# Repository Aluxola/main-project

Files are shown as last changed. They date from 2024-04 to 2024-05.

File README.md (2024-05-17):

# main-project
# Micro-mouse System Power and Sensor Subsystems
# Overview
This repository contains the design and implementation files for the Power and Sensor subsystems of a robotic system developed as part of the EEE3088F_2024 project. The Power subsystem manages power distribution, voltage regulation, and battery management, while the Sensor subsystem handles sensing and feedback for the robot's environment.

# Power Subsystem Features
Power distribution to motors and electronic components
Voltage regulation for stable operation
Battery management functions for efficient use
Current limiting and safety features
Power switching capabilities for control
Efficiency optimization for energy savings
# Sensor Subsystem Features
Wall sensing using infrared sensors
LED indicators for wall detection
Interface with the processor board for feedback
Low power consumption design
Reliability and accuracy in sensing wall proximity
# Contents
## Power Module:
### Schematics: 
Contains the schematic diagrams of the power module circuitry.
### PCB Design: 
Includes the PCB layout design files for manufacturing the power module.

## Sensor Module:
### Schematics: 
Contains the schematic diagrams of the sensor module circuitry.
### PCB Design: 
Includes the PCB layout design files for manufacturing the sensor module.
### Code: 
Firmware or software code for interfacing the sensor module with the processor board.
## Requirements
### Hardware: 
List of components required for building the power and sensor modules.
### Software: 
Tools and software required for programming, testing, and interfacing with the modules.

# Contributors
Alulutho Mthitshana

Tlangelani Tembe

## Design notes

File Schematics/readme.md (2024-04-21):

This is where our schematics are uploaded.

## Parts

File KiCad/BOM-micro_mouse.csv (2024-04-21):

Comment | Designator | Footprint | LCSC
10uF | C1,C4 | C_0603_1608Metric | C19702
1K | R2,R4,R5 | R_0603_1608Metric | C21190
JS102011SAQN | S1 | SW_JS102011SAQN | C221660
1.2K | R1 | R_0603_1608Metric | C22765
LED | D2 | LED_0603_1608Metric | C2286
LED | D1 | LED_0805_2012Metric | C2297
2.2uF | C2 | C_0603_1608Metric | C23630
2.2K | R3 | R_0603_1608Metric | C4190
DRV8833PW | U2 | SOP65P640X120-16N | C50506
0.01uF | C3 | C_0603_1608Metric | C57112
TP4056 | U1 | SOP127P600X175-9N | C725790

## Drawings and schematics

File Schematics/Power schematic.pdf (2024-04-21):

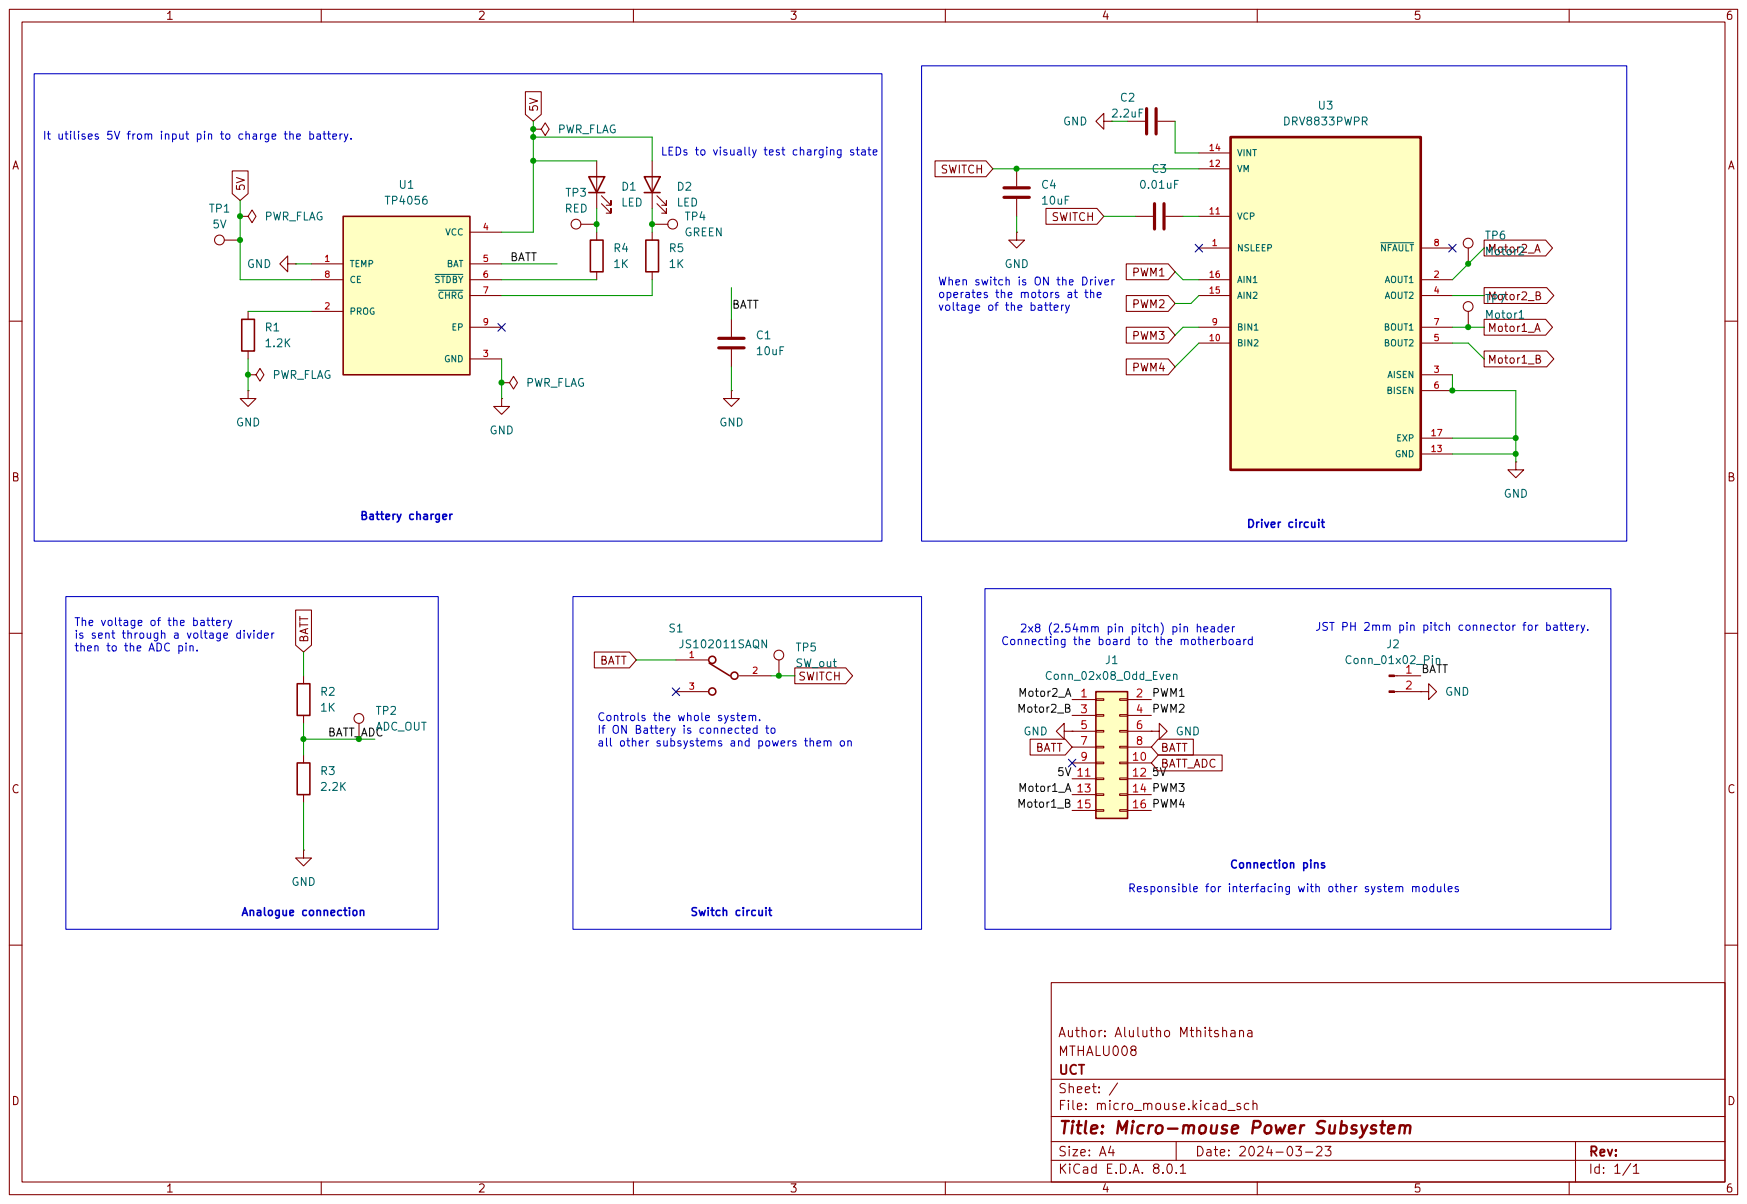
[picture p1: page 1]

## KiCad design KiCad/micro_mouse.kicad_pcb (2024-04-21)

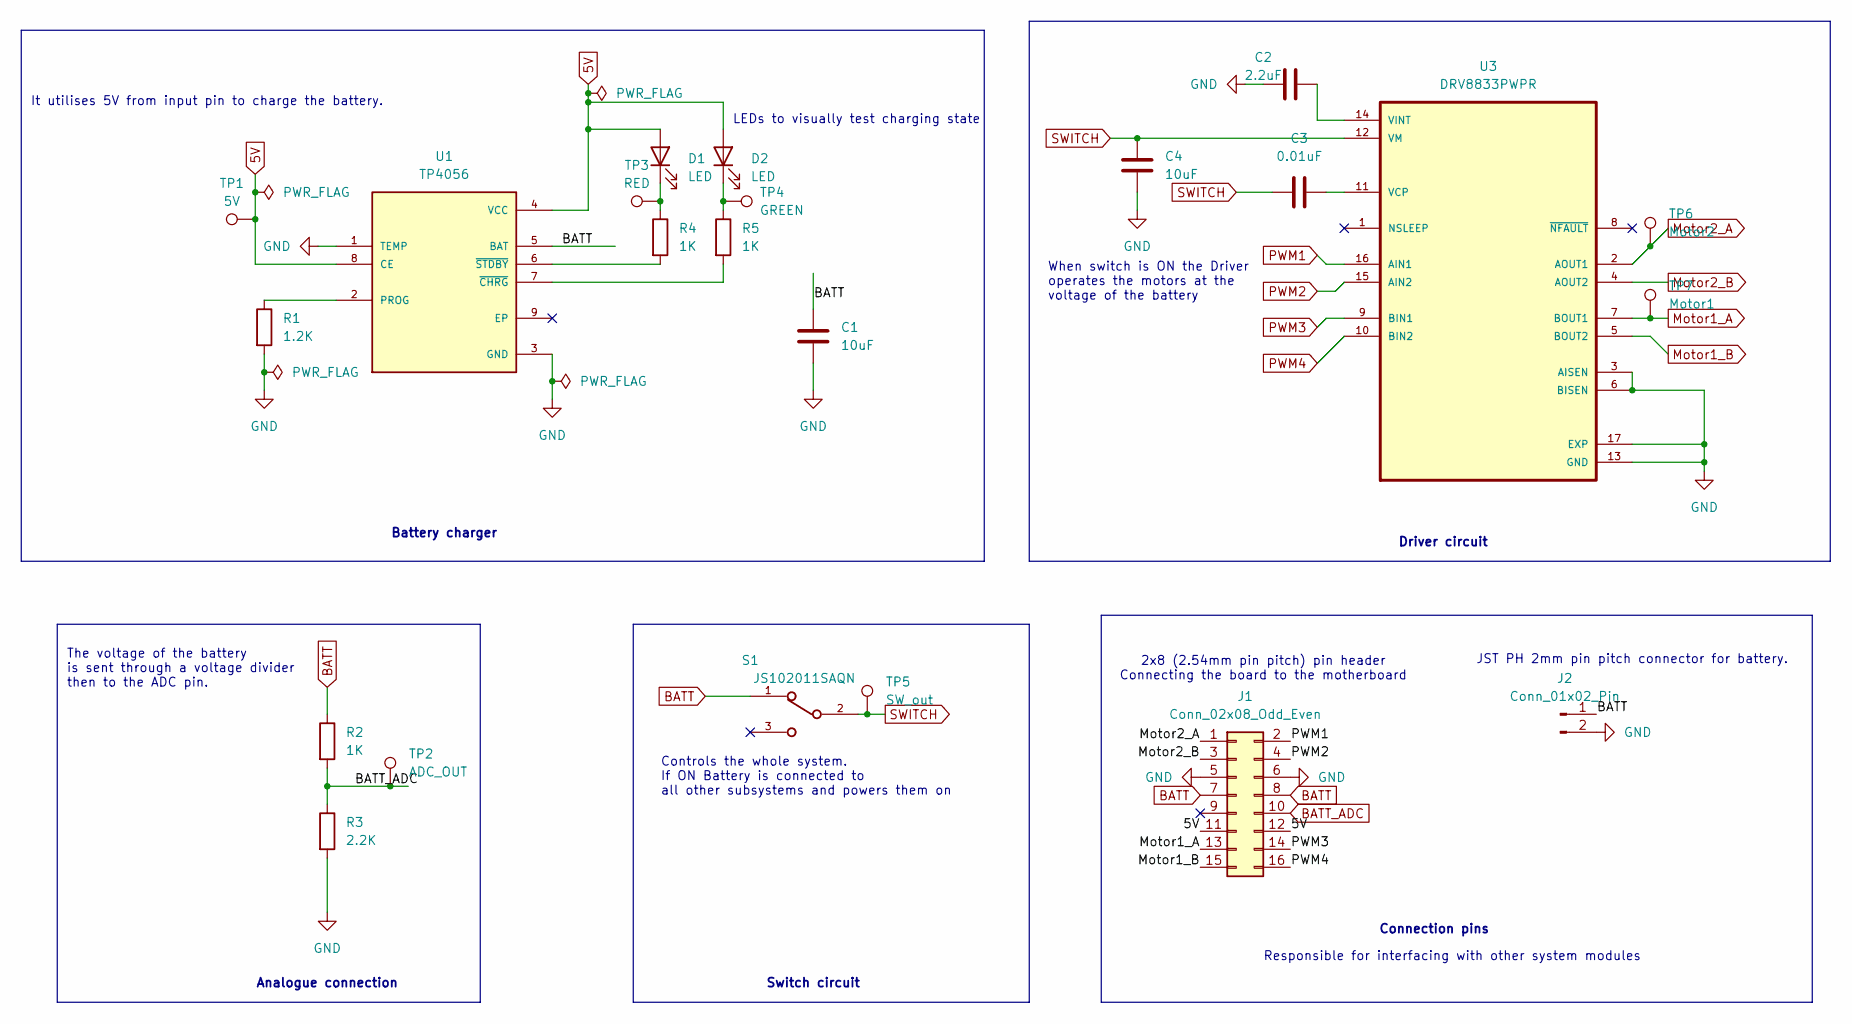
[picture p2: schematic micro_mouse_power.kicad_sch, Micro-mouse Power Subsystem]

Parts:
C1, C4: 10uF; C_0603_1608Metric
C2: 2.2uF; C_0603_1608Metric
C3: 0.01uF; C_0603_1608Metric
D1: LED; LED_0805_2012Metric
D2: LED; LED_0603_1608Metric
J1: Conn_02x08_Odd_Even; PinHeader_2x08_P2.54mm_Vertical
J2: Conn_01x02_Pin; JST_PH_B2B-PH-K_1x02_P2.00mm_Vertical
R1: 1.2K; R_0603_1608Metric
R2, R4, R5: 1K; R_0603_1608Metric
R3: 2.2K; R_0603_1608Metric
S1: JS102011SAQN; SW_JS102011SAQN
TP1: 5V; TestPoint_Pad_D1.5mm
TP2: ADC_OUT; TestPoint_Pad_D1.5mm
TP3: RED; TestPoint_Pad_D1.5mm
TP4: GREEN; TestPoint_Pad_D1.5mm
TP5: SW_out
TP6: Motor2; TestPoint_Pad_D1.5mm
TP7: Motor1; TestPoint_Pad_D1.5mm
U1: TP4056; SOP127P600X175-9N
U3: DRV8833PWPR; SOP65P640X120-16N; PARTREV E

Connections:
5V: D1.2 (A), D2.2 (A), J1.11, J1.12, TP1.1, U1.4 (VCC), U1.8 (CE)
BATT: C1.2, J1.7, J1.8, J2.1, R2.1, S1.1, U1.5 (BAT)
BATT_ADC: J1.10, R2.2, R3.1, TP2.1
GND: C1.1, C2.1, C4.2, J1.5, J1.6, J2.2, R1.2, R3.2, U1.1 (TEMP), U1.3 (GND), U3.3 (AISEN), U3.6 (BISEN), U3.13 (GND), U3.17 (EXP); also elsewhere on the board
Motor1_A: J1.13, TP7.1, U3.7 (BOUT1); also elsewhere on the board
Motor1_B: J1.15; also elsewhere on the board
Motor2_A: J1.1, TP6.1, U3.2 (AOUT1); also elsewhere on the board
Motor2_B: J1.3; also elsewhere on the board
unnamed: D1.1 (K), R4.1, TP3.1
unnamed: D2.1 (K), R5.1, TP4.1
unnamed: R1.1, U1.2 (PROG)
unnamed: R5.2, U1.7 (~CHRG)
unnamed: R4.2, U1.6 (~STDBY)
unnamed: C3.2, U3.11 (VCP)
unnamed: C2.2, U3.14 (VINT)
PWM1: J1.2; also elsewhere on the board
PWM2: J1.4; also elsewhere on the board
PWM3: J1.14; also elsewhere on the board
PWM4: J1.16; also elsewhere on the board
SWITCH: C3.1, C4.1, S1.2, TP5.1, U3.12 (VM); also elsewhere on the board

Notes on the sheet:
Battery charger
2x8 (2.54mm pin pitch) pin header Connecting the board to the motherboard
Switch circuit
The voltage of the battery is sent through a voltage divider then to the ADC pin.
Controls the whole system. If ON Battery is connected to all other subsystems and powers them on
It utilises 5V from input pin to charge the battery.
LEDs to visually test charging state
Analogue connection
JST PH 2mm pin pitch connector for battery.
Driver circuit
Responsible for interfacing with other system modules
Connection pins
When switch is ON the Driver operates the motors at the voltage of the battery

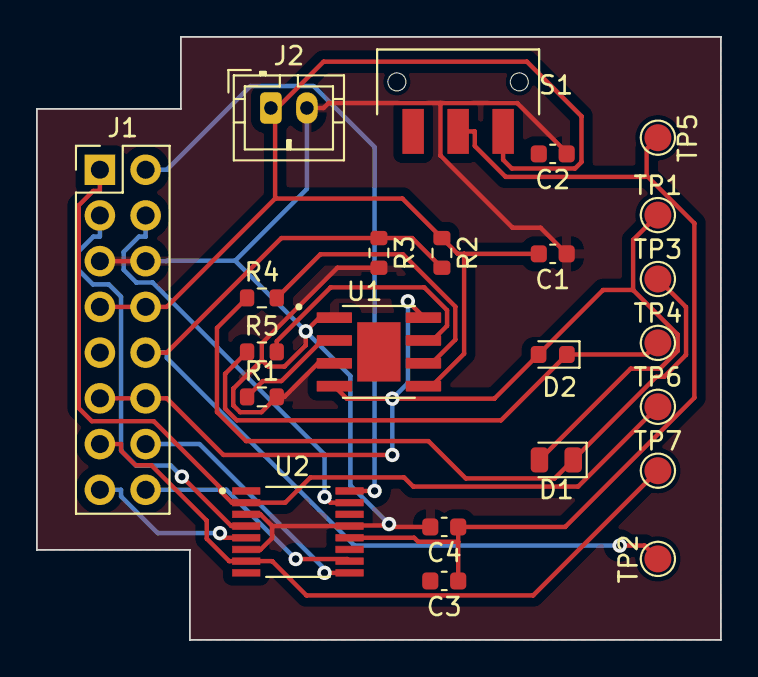
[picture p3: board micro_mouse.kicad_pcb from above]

Board: 2 copper layers, 38.0 x 33.5 mm, 23 parts (0 on the bottom side), 18 nets.

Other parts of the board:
U2: DRV8833PW; SOP65P640X120-16N

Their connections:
GND: U2.3 (A_ISENSE), U2.6 (B_ISENSE), U2.13 (GND); also elsewhere on the board
Motor1_A: U2.7 (B_OUT1); also elsewhere on the board
Motor1_B: U2.5 (B_OUT2); also elsewhere on the board
Motor2_A: U2.2 (A_OUT1); also elsewhere on the board
Motor2_B: U2.4 (A_OUT2); also elsewhere on the board
PWM1: U2.16 (A_IN1); also elsewhere on the board
PWM2: U2.15 (A_IN2); also elsewhere on the board
PWM3: U2.9 (B_IN1); also elsewhere on the board
PWM4: U2.10 (B_IN2); also elsewhere on the board
SWITCH: U2.12 (VM); also elsewhere on the board

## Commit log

2024-04-21 Create Gerber Files
2024-04-21 Create PCB Production Files
